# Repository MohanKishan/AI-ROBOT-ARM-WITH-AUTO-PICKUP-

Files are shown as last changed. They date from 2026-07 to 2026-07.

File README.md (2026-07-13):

3D Printed 4-DOF Robot Arm with Real-Time 3D Visualization & Auto Pickup
A Raspberry Pi 4B-controlled 4-DOF robot arm with a web-based 3D interface built on Three.js.

Hardware
Base — DEAO 20kg digital servo on GPIO 16.
Arm — Pro-Range DS5160 60kgcm servo on GPIO 18.
Wrist — GS5508MG 55kg servo on GPIO 23.
Gripper — MG996R DC motor (pot removed) on an IBT-4 (BTS7960) H-bridge. RPWM on GPIO 25, LPWM on GPIO 26. INA219 current sensor on I2C (0x40) for stall detection.
Depth sensor — VL53L1X on I2C (0x29).
Camera — USB webcam for YOLOv8 vision.

Software Stack
Server — Python HTTP on port 8081. Serves a single HTML page with Three.js 3D visualization.
Detection — YOLOv8n for object identification.
IK — 2-link inverse kinematics with full path planning (hover → descend → grip → lift).
FK — Calibrated 6-point interpolated lookup table mapping arm angle to shoulder position.
Gripper control — INA219 monitors current in real time. Motor runs until stall is detected (500mA threshold), then holds torque at 25% duty cycle. Open command coasts freely. 0.8s startup delay ignores inrush current spike.

Key Features
Autonomous pickup — Voice or web UI triggers YOLO detection, IK path planning, and center-grab alignment. Objects beyond 34cm are rejected. FOV-based centering corrects base and arm angles for accurate grabs.
3D digital twin — Live Three.js model mirrors all joints in real time. Ghost arms show planned path during pickup sequences.
Voice commands — Chrome Web Speech API with fuzzy Levenshtein matching filters background noise. Supports "pick up [object]", "home", "wave", "open/close gripper".
Safety — Floor collision avoidance, joint limit enforcement, emergency stop button, servo hold refresh thread.

Architecture
The Pi runs a lightweight HTTP server hosting a single-page app with Three.js 3D rendering, voice recognition, and WebSocket communication. GPIO PWM drives servos directly. The IBT-4 H-bridge provides raw DC motor control for the gripper. Arduino Nano handles PID feedback for the arm joint via USB serial.

The step up guide file has all the step by step instructions on how to use the arm 
Most of the software was developed with the assistance of AI. The hardware design, system integration, calibration, and testing were completed by me.
A picture of the arm.

The wrist GS5508MG 55 kg servo is cooled using a heatsink and a small fan.
on the input of the power rail of servo I am using 4700 uf cap.
and the external power supply of the servo is in this fashion.
Power Supply

Old Computer PSU (12 V rail)
        │
        ▼
600 W Buck Converter
(12 V → 8.3 V)
        │
        ▼
Servo Power Rail
Picture of it 


Picture of the web interface.
WhatsApp Image 2026-07-08 at 8 11 39 PM

The robot arm uses this 3D-printable gripper:
https://cults3d.com/en/3d-model/various/robot-gripper-flexible-servo-mg995-mg996r

YouTube Demo – Autonomous Object Pickup.
https://youtube.com/shorts/DapBP4Frb9c

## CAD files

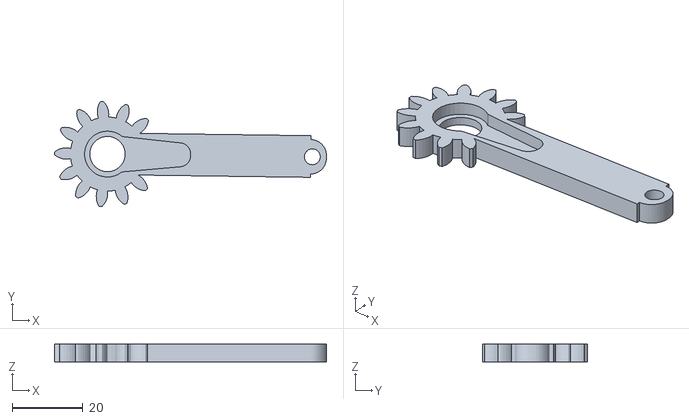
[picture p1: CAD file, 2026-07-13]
Stl Files/servo gear for gripper.stl
77.0 x 29.9 x 5.00

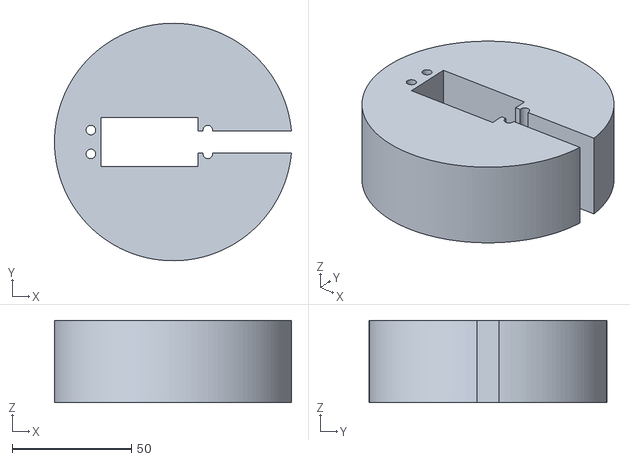
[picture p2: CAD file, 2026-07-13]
Stl Files/Base servo holder.stl
99.3 x 99.5 x 34.5

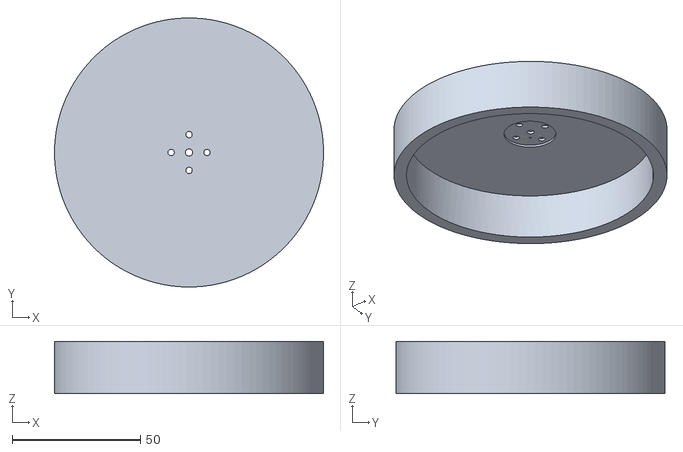
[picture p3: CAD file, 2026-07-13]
Stl Files/Base mount.stl
105.0 x 105.0 x 20.3

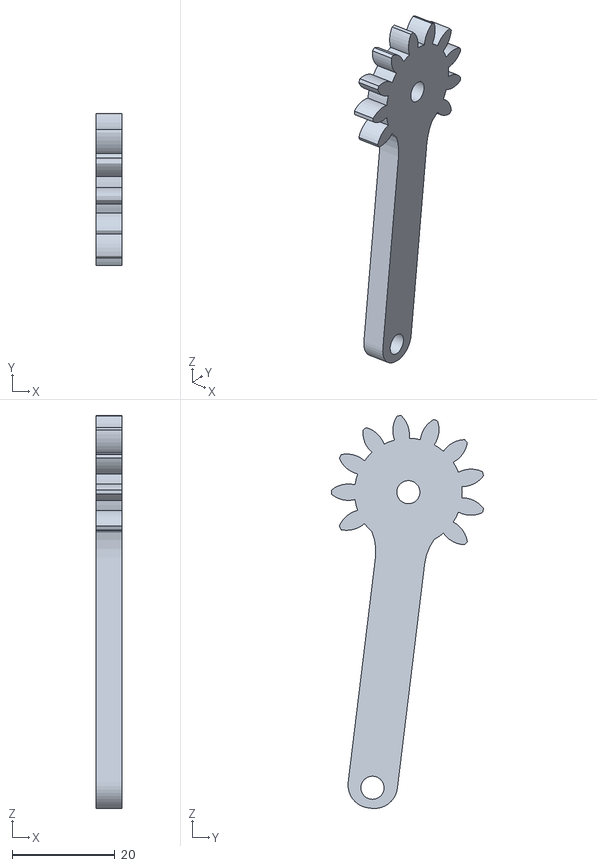
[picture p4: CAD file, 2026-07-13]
Stl Files/Gear for gripper.STL
5.00 x 29.6 x 76.6

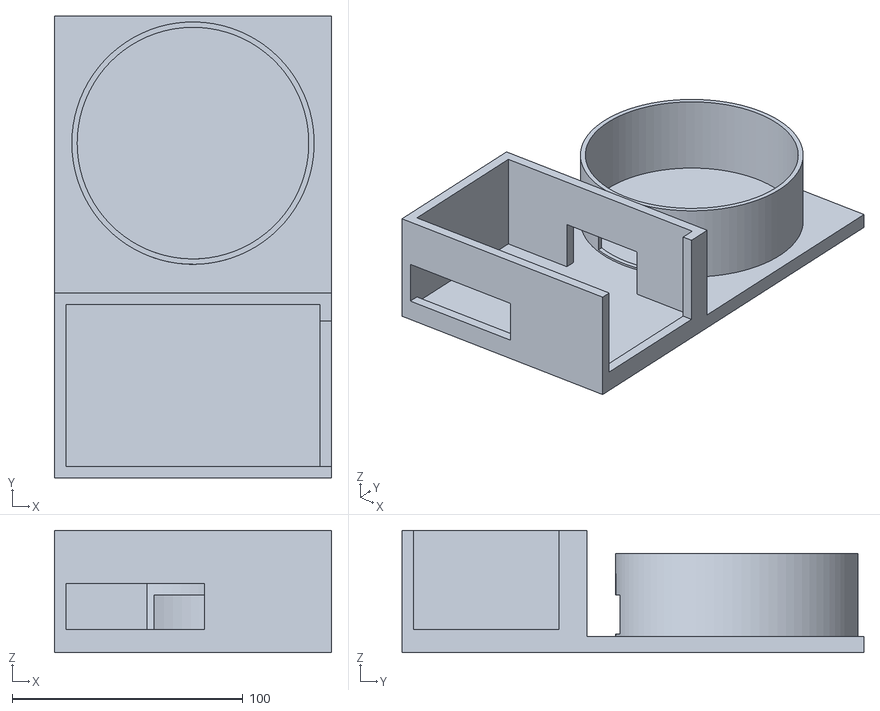
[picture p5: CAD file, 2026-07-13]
Stl Files/PI holder_.stl
120.0 x 200.0 x 53.0

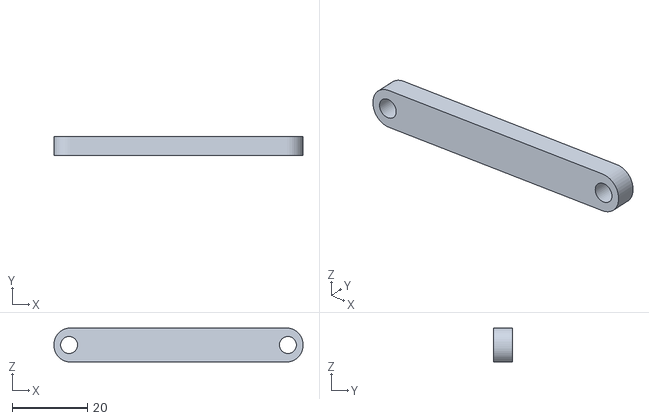
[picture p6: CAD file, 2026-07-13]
Stl Files/ConectorPin x2.STL
66.0 x 5.00 x 9.00

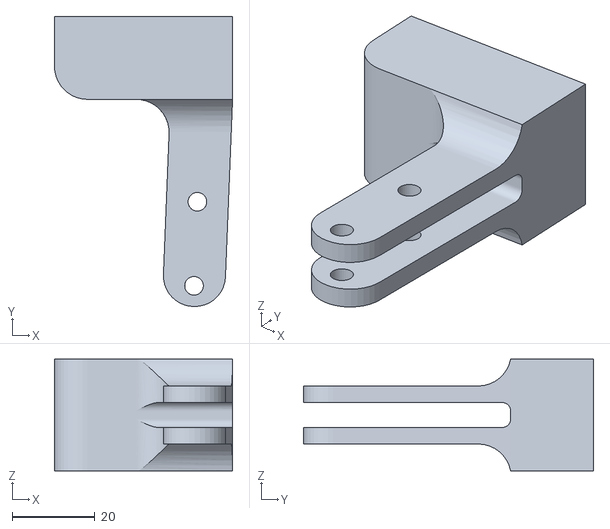
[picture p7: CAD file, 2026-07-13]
Stl Files/Gripper holder x2.STL
43.0 x 70.0 x 27.0

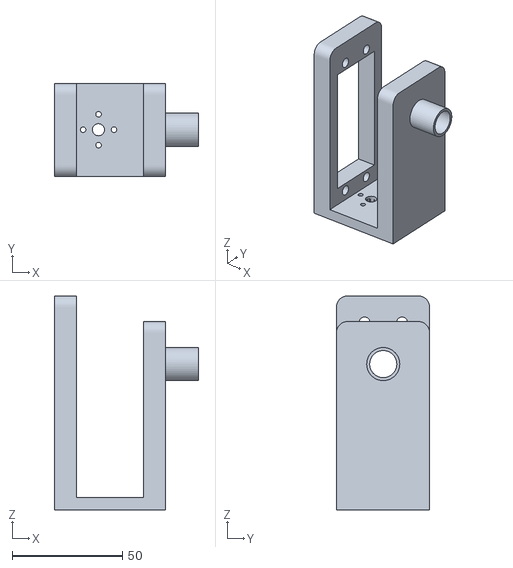
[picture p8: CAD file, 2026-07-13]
Stl Files/upper base.stl
65.3 x 42.3 x 97.0

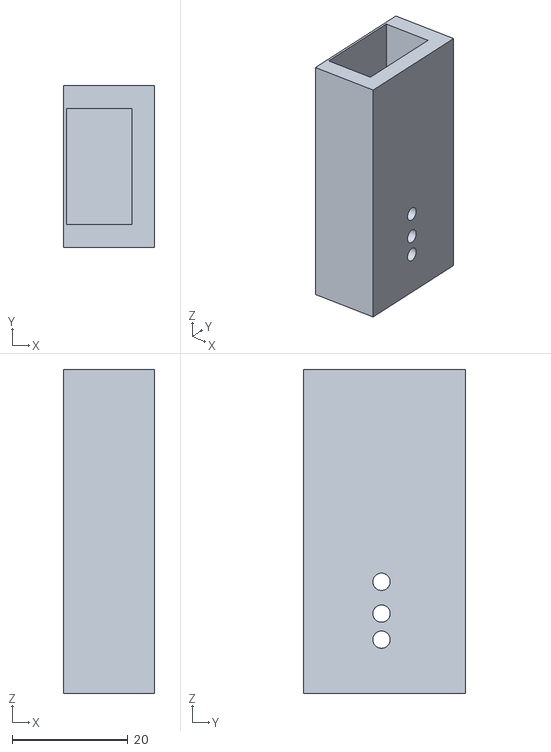
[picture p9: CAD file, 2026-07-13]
Stl Files/Wrist holder_.stl
15.6 x 27.9 x 56.0

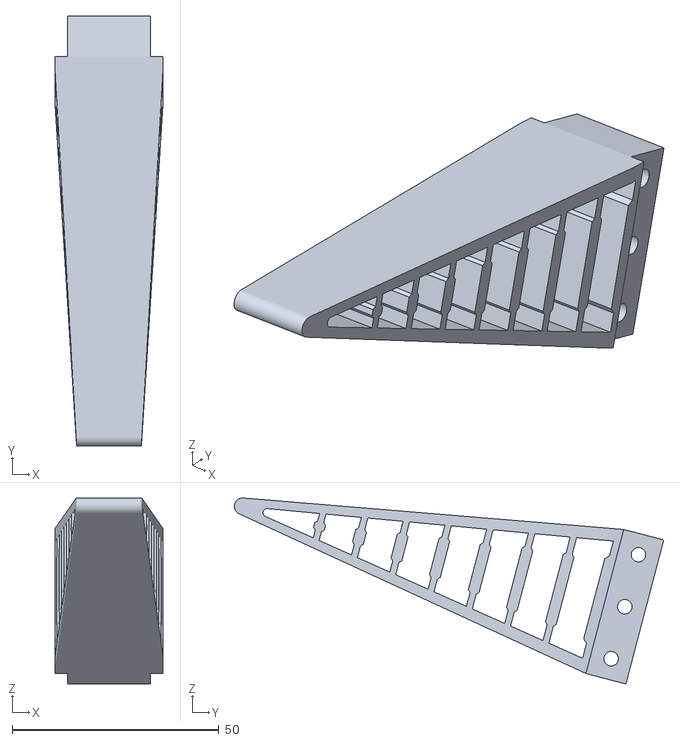
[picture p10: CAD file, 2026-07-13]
Stl Files/Gripper x2.STL
26.0 x 103.8 x 44.9

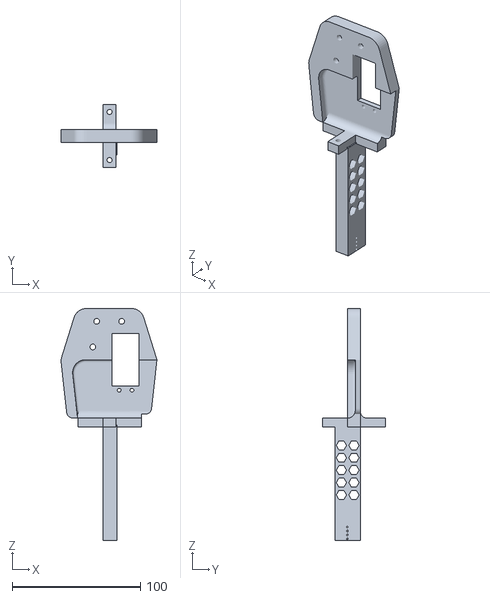
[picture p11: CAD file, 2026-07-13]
Stl Files/gripper+arm.stl
74.8 x 49.5 x 181.0

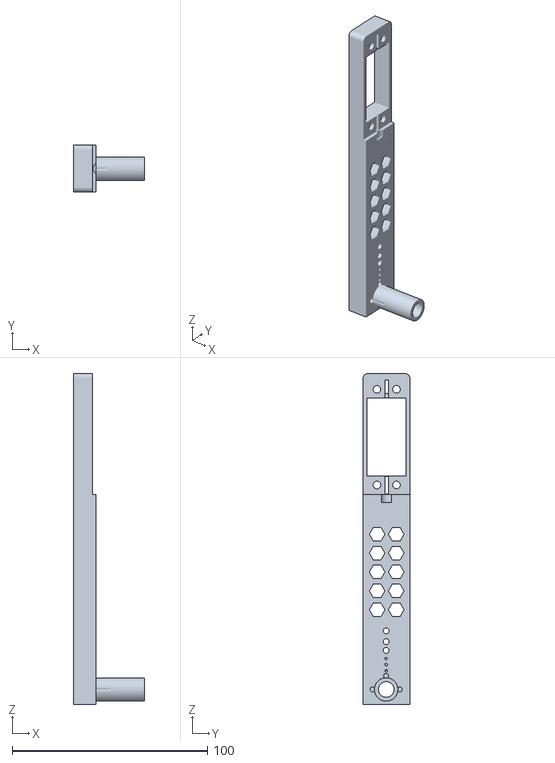
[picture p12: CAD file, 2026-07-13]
Stl Files/Arm_.stl
36.6 x 24.0 x 169.5

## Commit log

2026-07-10 Enhance README with arm setup details and images
    Added images and details about the arm setup, including power supply and gripper information.
2026-07-10 Revise README for servo cooling and power supply details
    Updated descriptions for the wrist servo cooling and power supply setup.
2026-07-10 Update README with images and video links
    Added images of the web interface and the servo setup.
2026-07-13 Add STL FILES to Stl Files directory
